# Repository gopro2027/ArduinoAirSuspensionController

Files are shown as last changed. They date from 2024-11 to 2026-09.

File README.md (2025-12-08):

# Open Air Suspension Management (OAS-Man)
(https://oasman.dev) 
<!---![image](https://github.com/user-attachments/assets/ea535981-4f51-4782-8f93-9eb1126dc81b)-->

###  [ discord icon Please click here to join the Discord server](https://discord.gg/pUf7FmHKpg) 
###  [ tutorial icon Click here to view the comprehensive build tutorial and documentation!](https://oasman.dev)
###  [ update icon Click here for the oasman installer/update page](https://oasman.dev/flash)

### Important Info To Potential Creators:
Please join the discord for more specific information before you built it!<br>
There may be important information to share before you begin purchasing parts.<br>

### Overview:
This is intended as a DIY replacement for products such as Airlift 3P/3H ($1500) or Airtek Stage 2+ ($1000) with a build cost of less than $500. Combined with the customizability of open sourced code, I hope this is a tempting option for some DIY-ers out there.<br>
Our goal with this project is to provide the car community with a modern fully customizable well documented air suspension system with a budget build cost in mind, all not bound by the limitations of a single company. The rest of your car is custom to you, why not your air suspension too?<br>
- Want to customize the app to match your ride? You got it.<br>
- Did your proprietary air suspension software stop working and there's no update? Not an issue here!<br>
- Sensor broke in your proprietary manifold and you have to buy a whole new one for $1000? Not an issue here, just replace the sensor for $10.<br>
- Want to use bespoke heavy duty valves but also have a nice user interface? Look no further than OAS-Man!<br>
- Control your system with a PS3/PS4/Xbox controller? Yep, [we have that](https://www.youtube.com/shorts/fbXJVwzc6P0)<br>
- Restomodding an old air suspension system? OAS-Man may be the solution!<br>
- Literally any idea you've ever wanted to try with air suspension? OASMan is the best place to start.<br>

This github repo includes an android app<sup>1</sup> and esp32 code along with some 3d printable files and a PCB. The PCB is pre-made SMD and ready for upload in JLCPCB with assembly so minimal-to-no soldering required. There is also a pre-made touch screen device you can order ($25 to $40) which is used as the dedicated controller<sup>2</sup>. There is an easy to use webpage to upload the software so there is no coding required. You will still need to supply the rest of your system which is not covered in this project, such as struts/bags, tank, compressor, tubing and fittings, ect. So that is what you would need in addition to this, similarly to what you would need for one of the on-the-shelf manifolds. If you are unsure what to purchase, I suggest referencing (or purchasing!) the [Airtekk Stage 1 Kit](https://www.airtekk.com/product-p/uni-stage1-kit.htm) as that will just about cover everything you need.<br>
<sub>1. The mobile app is behind on development and lacks various features of the controller software, and currently only has an android release. Recommended to use the touch screen controller for full functionality.</sub><br>
<sub>2. Please view the tutorial and build instructions for more info.</sub>

### Branch Information:
**main branch = ESP32** (Current full version of OASMan)<br>
**dev branch = ESP32** (Bleeding edge updates to OASMAN)<br>
**nano-v1 branch = Arduino Nano** (outdated, no longer maintained, only exists for legacy purposes)<br>
**Other branches = current dev work** (Other dev work which you can ignore)<br>
<br>
### Folder Information:
**tutorial** - Contains important build instructions (must read)<br>
**OASMan_ESP32** - The main board project<br>
**Wireless_Controller** - The project for the wireless controller of the main board<br>
**builds** - Mobile App Builds (apk's ect)<br>
**ESP32_SHARED_LIBS** - Contains files used between the main board and controller projects. Notably the config file which you may or may not need to edit.<br>
**LCDImageCreatorTool** - Code generator for making images for the tiny 128x64 screen on the manifold.<br>
**MobileApp** - New flutter mobile app using BLE (incomplete at the time of this writing)<br>
**3d Prints** - Contains files for 3d printing (more info in tutorials)<br>
**PCB** - PCB files. More info in tutorial<br>
**PS3_Controller_Tool** - Contains instructions & exe for setting the MAC address of your ps3 controller to work with OASMan<br>
**photos** - photos<br>
<br>

<br>

<!---
**Loose steps:** <br>
1. Order parts, order circuit board on JLPCB website, 3d print parts
2. Solder parts to circuit board, flip all switches to off
    1. For the manifold connector, wire the white wires (abcdefgh) in alphabetical order on the board, so 1 is a, 2 is b, and so on. The 9th wire goes to the spot right above the rest of the wires.
    2. The pressure sensors go in order... 1(manifold) -> FP (board) ... 4 -> RD. In general the order of everything is FRONT PASSENGER, REAR PASSENGER, FRONT DRIVER, REAR DRIVER abbreviatted FP, RP, FD, RD, sorry for the odd order it happened by accident
4. Configure code:
    1. get mac address of HC-06 bluetooth device by using an app or sommething to find it.
    2. Put the mac address in the android code, replacing the old mac address
    3. (Optional) Update the passwords in the app and arduino code if you want
    4. Write code to arduino
5. Circuit board single switch off, on the double switch make the top one on and bottom one off (this will power the arduino by 5v from the buck converter. 12 is bottom switch if you want to use that instead but you can ignore it)
-->
OAS-Man Final v2
<!--![wireless_contoller](https://github.com/user-attachments/assets/ef3c085b-e8ef-4365-bd6b-093a90eec54d)
![manifold](https://github.com/user-attachments/assets/d93784e5-7e5e-4bb0-891a-8a2a8e4d4da0)
![app_airsuspension](https://user-images.githubusercontent.com/7937950/236578835-0e3a208d-48cf-48e8-a882-4479f1afe35c.png)-->
<!--![car_airsuspension](https://user-images.githubusercontent.com/7937950/236578918-bfa39ad6-a3b5-4d52-b36a-be34e8c608af.png)-->
<!--![oasman mascot car](https://github.com/user-attachments/assets/aef9e896-0be0-4203-92d2-81836c27fd5d)-->

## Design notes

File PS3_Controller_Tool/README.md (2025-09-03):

# Videogame Controller Usage
OASMan implements a library called [Bluepad32](https://bluepad32.readthedocs.io/en/latest/) in order to allow a multitude of controllers to connect to our air suspension system!

<br>
Thank you to [ricardoquesada](https://github.com/ricardoquesada/bluepad32) for the creation of this library!

### How to pair a controller
DISCLAIMER: Always store controllers in a safe location when driving so they do not get enabled accidentally while driving. Do not use controllers while driving. Use at your own risk.
1. Put your car in park for pairing. Pairing a new controller may potentially disrupt bluetooth signal, and in the worst case, cause oasman to reboot. This shouldn't pose any safety issues, but please be careful.
3. You need to go into your oasman touch screen control and go to settings and click "Allow New Controller". This will put oasman into pairing mode.
4. Grab your controller and follow the manufacturers instructions on how to put it into pairing/sync mode. You can also find instructions for this on [bluepad32's wiki](https://bluepad32.readthedocs.io/en/latest/supported_gamepads/)
Sometimes there may be issues during syncing new controllers. You may find better results if you disconnect other controllers before trying to sync a new controller.

Once your controller is paired, to reconnect it again, simply turn it on like normal and oasman will accept the connection.

There is an arbitrarily chosen max of 20 paired controllers in OASMan. You can reset all paired controllers in the settings page of the touch screen controller.

Oasman technically supports multiple controllers being connected at the same time.

Not all controllers are supported, such as keyboards, but I did specifically add [support for the wii fit balance board](https://www.instagram.com/p/DNy50Yu3hv6/)

### Special instructions for PS3 Controllers
If you plan to use a ps3 controller, use the sixaxis pair tool to change your mac address of your PS3 controller to your ESP32's mac address<br>
You can use a phone app called nRF Connect to obtain the mac address of the oasman system<br>
<br>

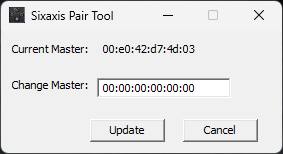
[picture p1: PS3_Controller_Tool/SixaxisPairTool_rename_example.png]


<a href="https://github.com/gopro2027/ArduinoAirSuspensionController/raw/refs/heads/main/PS3_Controller_Tool/SixaxisPairToolSetup-0.3.1.exe">Download Sixaxis Pair Tool here</a><br>
<br>
Additional information that explains why the ps3 controller is special and linux setup: <a href="https://bluepad32.readthedocs.io/en/latest/pair_ds3/">https://bluepad32.readthedocs.io/en/latest/pair_ds3/</a><br>
<br>
### Controller Controls
**L1 + R1**: arm/disarm the controller (armed by default)<br>
**System Button (aka playstation button or xbox button)**: disconnect controller<br>
<br>
Joystick inputs:<br>
**left joystick - left**: air up left side of car<br>
**left joystick - right**:  air out left side of car<br>
**left joystick - up**: air up front side of car<br>
**left joystick - down**: air down front side of car<br>
**right joystick - left**: air out right side of car<br>
**right joystick - right**: air up right side of car<br>
**right joystick - up**: air up rear side of car<br>
**right joystick - down**: air down rear side of car<br>
<br>
**Controllers with only one joystick**: Devices such as the nintendo switch joycon, you can press and hold the **B** button to make your joystick swap from one side to the other while holding it.<br>
<br>
**Wii Fit Balance Board**: Left side controls front of car, right side controls rear of car<br>
<br>
There is also an easter egg. See if you can find it!<br>

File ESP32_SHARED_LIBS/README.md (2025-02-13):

This project is not meant to be compiled and uploaded to an esp32.<br>
This simply contains shared files between the manifold and the controller.<br>
You edit the user_defines.h file in here

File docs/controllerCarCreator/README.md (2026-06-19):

# OAS-Man Car Editor

Web tool for aligning a custom car photo over the controller preset images and uploading
custom car/wheel graphics to the Wireless Controller over USB serial, or exporting
ready-to-compile LVGL C sources for developers. Replaces the Python Tkinter tool at
`Wireless_Controller/tools/imageCreator/car_creator.py`.

The shipped page, `index.html`, is **generated** — don't edit it by hand. Edit the
source files and rebuild.

## Building `index.html`

Requires [Node.js](https://nodejs.org/) (v18+).

```bash
# from docs/controllerCarCreator/
npm install      # one-time: installs esbuild
npm run build    # compiles app.tsx + template.html + preset PNGs -> index.html
```

That's it. `index.html` is a standalone file — open it in Chrome or Edge (no local
server needed). Preset reference images are embedded at build time from
`Wireless_Controller/device_libs/<device>/images/presets/`.

### Rebuild automatically on change

```bash
npm run watch    # rebuilds index.html whenever app.tsx or template.html changes
```

## How the build works

```
app.tsx ────────────────┐
                        ├──►  build.mjs (esbuild + preset embed)  ──►  index.html
template.html ──────────┤
device_libs presets ────┘
```

- **`app.tsx`** — the React app and workflow logic. **Source of truth for behavior.**
- **`template.html`** — the HTML shell: `<head>`, CSS, CDN `<script>` tags (React,
  ReactDOM), preset placeholder, and `<div id="root">`.
- **`build.mjs`** — transpiles/minifies `app.tsx`, scans `device_libs` for preset PNGs,
  base64-embeds them as `window.PRESET_IMAGES`, and writes `index.html`.

## Upload to controller (recommended)

Requires firmware with USB car upload support (current `dev` controller builds).

1. Complete the align-car and align-wheels steps in the editor.
2. On the controller: **Settings → Upload custom car (USB)** → confirm reboot.
3. Plug the controller into your computer with USB.
4. In the editor (Chrome or Edge, `https://` or localhost): **Connect serial** → **Upload to device**.
5. The controller reboots with your custom car on the presets screen.

Custom images are stored on the controller's **LittleFS** flash partition and survive OTA firmware updates.

To remove USB-uploaded images: **Settings → Clear custom car images**.

## Developer fallback (compile-time)

1. Download `img_car_custom.c` and `img_wheels_custom.c` from the editor.
2. Copy them into `Wireless_Controller/src/`.
3. Uncomment `-D CUSTOM_CAR_IMAGE` in `Wireless_Controller/platformio.ini`.
4. Build and flash your controller env.

The editor converts images to **LVGL RGB565A8** in the browser (same format as
[lvgl.io/tools/imageconverter](https://lvgl.io/tools/imageconverter)).

## Files

| File | Committed? | Notes |
| --- | --- | --- |
| `app.tsx` | yes | React source |
| `template.html` | yes | HTML shell + CSS |
| `build.mjs` | yes | Build script + preset bundler |
| `index.html` | yes | **Generated** — do not hand-edit |
| `HOW_IT_WORKS.md` | yes | In-depth architecture doc |
| `node_modules/` | no | gitignored |

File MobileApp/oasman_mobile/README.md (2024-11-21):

# oasman_mobile

A new Flutter project.

## Getting Started

This project is a starting point for a Flutter application.

A few resources to get you started if this is your first Flutter project:

- [Lab: Write your first Flutter app](https://docs.flutter.dev/get-started/codelab)
- [Cookbook: Useful Flutter samples](https://docs.flutter.dev/cookbook)

For help getting started with Flutter development, view the
[online documentation](https://docs.flutter.dev/), which offers tutorials,
samples, guidance on mobile development, and a full API reference.

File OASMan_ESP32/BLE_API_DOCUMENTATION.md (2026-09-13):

# BLE API Documentation - Client Implementation Guide

###### Notice: This documentation was written by AI. Please double check the code if you run into issues, and notify the maintainers

This document provides a complete guide for implementing a BLE client to connect to the OASMan ESP32 Air Suspension Controller. It is based on the implementation patterns used in the Wireless_Controller project.

## Table of Contents

- [Client Implementation Overview](#client-implementation-overview)
- [Complete Client Implementation](#complete-client-implementation)
- [Packet Queue System](#packet-queue-system)
- [Notification Handling](#notification-handling)
- [Sending Commands](#sending-commands)
- [Client State Management](#client-state-management)
- [API Reference](#api-reference)
  - [Service and Characteristics](#service-and-characteristics)
  - [Packet Types](#packet-types)
  - [Constants and Enums](#constants-and-enums)

---

## Client Implementation Overview

The client implementation follows these key patterns:

1. **Packet Queue System**: Thread-safe queue for sending commands (prevents blocking)
2. **Notification-Based Communication**: All responses arrive via characteristic notifications
3. **Status Monitoring**: Tracks connection health via periodic status updates
4. **Authentication Flow**: Must authenticate within 5 seconds of connection
5. **Connection Management**: Handles reconnection, timeouts, and state tracking

For a complete reference implementation, see the Wireless_Controller project code.

---

## Client Implementation Flow

### 1. Initialization

When initializing your BLE client:

- Initialize your BLE stack/library
- Set MTU to 517 bytes before connecting (if supported by your platform)
- Initialize your packet queue system (see Packet Queue System section)
- Set up state variables for tracking connection status, authentication state, and status timeout

**Key State Variables Needed:**

- Connection status flag
- Authentication result state
- Status timeout timestamp
- References to the three characteristics (Status, REST, Valve Control)

### 2. Scanning for Devices

Scan for OASMan devices advertising the service UUID `679425c8-d3b4-4491-9eb2-3e3d15b625f0`.

**Scan Process:**

- Use active scanning for better discovery results
- Filter scan results by checking if devices advertise the OASMan service UUID
- Optional: Maintain a blacklist of devices that previously failed authentication to avoid repeated connection attempts
- Store found devices for connection attempts
- Recommended scan duration: 5 seconds

**What to do with found devices:**

- Store them in a queue or list for connection attempts
- Filter out devices from your auth blacklist (if implemented)

### 3. Connection

Connect to a discovered OASMan device:

**Connection Steps:**

1. Create a BLE client instance
2. Set up security/authentication callbacks if your platform requires it
3. Connect to the device (use async connection if available, with a 1-second timeout)
4. Wait for connection to complete (check connection status in a loop with timeout)
5. If connection fails, cancel and retry

**After Connection:**

1. Discover the service using UUID `679425c8-d3b4-4491-9eb2-3e3d15b625f0`
2. Get references to the three characteristics:
   - Status: `66fda100-8972-4ec7-971c-3fd30b3072ac`
   - REST: `f573f13f-b38e-415e-b8f0-59a6a19a4e02`
   - Valve Control: `e225a15a-e816-4e9d-99b7-c384f91f273b`
3. Subscribe to notifications on all three characteristics (use the same callback for all)
4. Add small delays (50ms) between characteristic subscriptions if needed

**Connection Callbacks:**

- Implement connection/disconnection callbacks to track connection state changes
- Handle security/authentication callbacks if your platform requires them

---

## Packet Queue System

The packet queue system allows non-blocking command sending, which is essential for responsive applications. Instead of blocking while waiting for writes to complete, commands are queued and sent sequentially in your main loop.

### Queue Pattern

**Purpose:** Decouple command creation from BLE transmission to avoid blocking your application.

**How it works:**

1. Your application code creates packets and adds them to a queue (non-blocking operation)
2. Your main loop processes the queue and sends packets one at a time to the REST characteristic
3. Use thread-safe queue operations if your application uses multiple threads

**Queue Functions Needed:**

- `sendRestPacket(packet)` - Add a packet to the queue (called from anywhere)
- `getBTRestPacketToSend(packet)` - Retrieve next packet from queue (called from main loop)
- `clearPackets()` - Clear all queued packets (useful on disconnect/reconnect)

**Queue Size:** Recommended maximum of 10 packets to prevent memory issues and ensure timely command processing.

**Thread Safety:** If your application uses multiple threads, protect queue access with mutexes/semaphores. If single-threaded, simple flags or counters are sufficient.

---

## Notification Handling

All responses arrive via characteristic notifications. Use a single callback function to handle notifications from both Status and REST characteristics.

### Notification Callback Pattern

**Single Callback for All Characteristics:**

- Use one callback function for all three characteristics
- Check the characteristic UUID in the callback to determine which characteristic sent the notification
- Process data based on which characteristic it came from

### Status Characteristic Notifications

**When:** Received approximately every 250ms after authentication

**What to do:**

1. Reset your status timeout timer (set timeout to current time + 5 seconds)
2. Set `hasReceivedStatus = true` (track that you've received at least one status)
3. Parse the `StatusPacket` structure:
   - Extract wheel pressures from `args16()[0-3]` (Front Passenger, Rear Passenger, Front Driver, Rear Driver)
   - Extract tank pressure from `args16()[4]`
   - Extract AI percentage from `args8()[10]`
   - `args8()[11]` is reserved (formerly AI ready bitset; removed in manifold schema 5) and reads 0
   - Extract status bitset from `args32()[3]` and parse individual flags
4. Update your application state/UI with the new values

**Status Bitset Parsing:** Each bit represents a different status flag (see [StatusPacketBittset](#constants-and-enums) in API Reference). Extract individual flags using bit shifting: `(statusBits >> StatusPacketBittset::FLAG_NAME) & 1`

### REST Characteristic Notifications

**When:** Received as responses to commands you send, or for authentication responses

**What to do:**

1. Reset your status timeout timer
2. Cast the data to `BTOasPacket*` and check the `cmd` field
3. **If `cmd == AUTHPACKET`:**
   - Extract `authResult` from the packet
   - Update your authentication state
   - Store the authenticated device address if successful
4. **If authenticated and `cmd == PRESETREPORT`:**
   - Parse `PresetPacket` to extract profile pressures
   - Update your profile data storage
5. **If authenticated and `cmd == GETCONFIGVALUES`:**
   - Parse `ConfigValuesPacket` to extract all configuration values
   - Update your configuration display
6. **If authenticated and `cmd == UPDATESTATUSREQUEST`:**
   - Extract status string from the packet
   - Display firmware update status to user

**Important:** Only process command responses (PRESETREPORT, GETCONFIGVALUES, etc.) when `authenticationResult == AUTHRESULT_SUCCESS`.

---

## Sending Commands

Commands are sent via the packet queue system (see [Packet Queue System](#packet-queue-system)).

### Command Flow

1. Create the appropriate packet type with required parameters (see [Packet Types](#packet-types) in API Reference)
2. Add packet to queue using `sendRestPacket(packet)`
3. Your main loop retrieves packets from queue and writes them to the REST characteristic
4. Responses arrive via REST characteristic notifications (see [Notification Handling](#notification-handling))

### Common Command Patterns

**Air Control:**

- `AirupQuickPacket` - Load profile then air up (main method)

**Preset Management:**

- `PresetPacket` - Request preset data (returns via notification)
- `SaveCurrentPressuresToProfilePacket` - Save current pressures to a profile
- `ReadProfilePacket` - Load profile settings
- `BaseProfilePacket` - Set base profile

**Configuration:**

- `ConfigValuesPacket` - Get or set system configuration values
  - Set first parameter to `false` to read only
  - Set first parameter to `true` and fill values to save

**Feature Toggles (via ConfigValuesPacket):**

- Rise on start, maintain pressure, air-out on shutoff, height sensor mode, safety mode, AI enabled are set via `ConfigValuesPacket` with `setValues = true` and the appropriate bits in `configFlagsBits` (see ConfigFlagsBit enum).

**Wheel Pressure:**

See [Packet Types](#packet-types) section for complete list and parameter details.

### Direct Valve Control

Valves can be controlled directly via the Valve Control characteristic without using the packet system.

**Process:**

1. Maintain a 32-bit integer where each bit represents a valve (bit 0 = valve 0, bit 1 = valve 1, etc.)
2. Set bits to 1 to open valves, 0 to close valves
3. Only send when the value changes (optimization)
4. Write 4 bytes (little-endian uint32_t) directly to Valve Control characteristic
5. Server tracks previous state and only toggles valves that changed

**Example State Management:**

- Track previous valve state
- Compare current desired state with previous
- Only write to characteristic when state changes
- This reduces unnecessary BLE traffic

---

## Client State Management

### Main Loop Pattern

Your main loop should handle several tasks:

**When Connected:**

1. **Send Queued Packets:** Retrieve packets from queue and write to REST characteristic (one at a time)
2. **Update Valve Control:** Check if valve state changed, and if so, write to Valve Control characteristic
3. **Check Status Timeout:** If `hasReceivedStatus` is true and current time exceeds `timeoutMS`, disconnect (connection lost)
4. **Monitor Connection:** Check if connection is still active (some platforms provide `isConnected()` methods)

**When Not Connected:**

1. **Scan for Devices:** If scanning is allowed, start a scan
2. **Process Discovered Devices:** Attempt to connect to found devices from your queue/list
3. **Handle Reconnection:** If connection fails, retry or start new scan

**Connection State Checks:**

- Monitor connection status regularly
- Handle disconnection callbacks gracefully
- Clear packet queue on disconnect
- Reset state variables (authentication, status tracking, etc.)

### Status Timeout Management

**Purpose:** Detect when connection is lost even if BLE stack doesn't notify you immediately.

**How it works:**

1. Set `hasReceivedStatus = false` initially
2. On first status notification, set `hasReceivedStatus = true` and `timeoutMS = currentTime + 5000`
3. On each subsequent status notification, reset `timeoutMS = currentTime + 5000`
4. In main loop, check: if `hasReceivedStatus && currentTime > timeoutMS`, then disconnect

**Why:** Status updates arrive every ~250ms when connected. If no status is received for 5 seconds, the connection is likely lost.

### Disconnection Handling

**When disconnecting:**

1. Set connection state to disconnected
2. Stop any active scans
3. Clear packet queue
4. Reset state variables:
   - `connected = false`
   - `hasReceivedStatus = false`
   - `authenticationResult = AUTHRESULT_WAITING`
5. Clean up client resources (cancel connection, delete client instance)
6. Allow scanning again for reconnection
7. Optionally: Show user notification about disconnection reason (auth failed, timeout, etc.)

---

## API Reference

### Service and Characteristics

All packets sent via the REST characteristic use the `BTOasPacket` structure:

```cpp
struct BTOasPacket {
    uint16_t cmd;          // BTOasIdentifier enum value
    uint8_t sender;        // unused (0)
    uint8_t recipient;     // Recipient ID (0 for broadcast)
    uint8_t args[100];     // Payload data (variable length)
};
```

**Total Size**: 104 bytes (`BTOAS_PACKET_SIZE`)

**Note**: The `args` array can be accessed as different types:

- `args8()` - Access as `uint8_t` array
- `args16()` - Access as `uint16_t` array
- `args32()` - Access as `uint32_t` array

All multi-byte values are **little-endian**.

---

### Packet Types

### Client-to-Server Packets (Commands)

#### AUTHPACKET

**Command ID**: `22`  
**Purpose**: Authenticate with the device

**Structure**:

- `args32()[0]`: `uint32_t blePasskey` - Device passkey
- `args32()[1]`: `AuthResult authResult` - Set to `AUTHRESULT_WAITING` (0) for auth request

**Usage**:

1. Create packet with `authResult = AUTHRESULT_WAITING`
2. Write to REST characteristic
3. Server responds with same packet but `authResult` set to `SUCCESS` or `FAIL`

**Example**:

```cpp
AuthPacket packet(passkey, AUTHRESULT_WAITING);
// Write packet.tx() (104 bytes) to REST characteristic

---

#### SAVETOPROFILE

**Command ID**: `5`  
**Purpose**: Save current profile settings to specified profile index

**Structure**:

- `args32()[0]`: `int profileIndex` - Profile number to save to

---

#### READPROFILE

**Command ID**: `6`  
**Purpose**: Load pressure settings from specified profile

**Structure**:

- `args32()[0]`: `int profileIndex` - Profile number to read

**Response**: Server loads the profile internally (no packet response)

---

#### AIRUPQUICK

**Command ID**: `7`  
**Purpose**: Load profile then air up (main air up method)

**Structure**:

- `args32()[0]`: `int profileIndex` - Profile to load and air up to

---

#### BASEPROFILE

**Command ID**: `8`  
**Purpose**: Set the base profile

**Structure**:

- `args32()[0]`: `int profileIndex` - Profile to set as base

---

#### RAISEONPRESSURESET

**Command ID**: `11`  
**Purpose**: Enable/disable automatic raise when pressure is set

**Structure**:

- `args32()[0]`: `bool enable` - 1 to enable, 0 to disable

---

#### REBOOT

**Command ID**: `12`  
**Purpose**: Reboot the device

**Structure**: No parameters

---

#### CALIBRATE

**Command ID**: `13`  
**Purpose**: Calibrate system (feature unfinished)

**Structure**: No parameters

---

#### STARTWEB

**Command ID**: `14`  
**Purpose**: Start OTA update mode with WiFi credentials

**Structure**:

- `args[0-32]`: `char[]` - WiFi SSID (null-terminated, max `WIFI_SSID_MAX_LEN` = 32 bytes)
- `args[33-97]`: `char[]` - WiFi Password at `STARTWEB_PASSWORD_INDEX` (null-terminated, max `WIFI_PASSWORD_MAX_LEN` = 64 bytes; longer input is truncated)
- `args[98]`: `uint8_t` - `1` = allow a one-time insecure HTTP update (`STARTWEB_INSECURE_FLAG_INDEX`)

Breaking change from the old 50/50 split (`args[0-49]` / `args[50-99]`): manifold, controller and app must run matching firmware for STARTWEB.

**Example**:

```cpp
StartwebPacket packet("MyWiFi", "password123");
```

---

#### SAVECURRENTPRESSURESTOPROFILE

**Command ID**: `17`  
**Purpose**: Save current wheel pressures to a profile

**Structure**:

- `args32()[0]`: `int profileIndex` - Profile number to save current pressures to

---

#### PRESETREPORT

**Command ID**: `18`  
**Purpose**: Request pressure values for a specific profile

**Structure**:

- `args32()[0]`: `int profileIndex` - Profile to query

**Response**: Server responds with `PresetPacket` containing profile pressures

---

#### GETCONFIGVALUES

**Command ID**: `21`  
**Purpose**: Get or set system configuration values

**Structure**:

- `args32()[0]`: `uint32_t systemShutoffTimeM` - System shutoff time in minutes
- `args32()[1]`: `uint32_t configFlagsBits` - User config flags (see ConfigFlagsBit enum)
- `args16()[4]`: `uint16_t pressureSensorMax` - Maximum pressure sensor value
- `args16()[5]`: _retired_ (formerly `bagVolumePercentage`) 
- `args8()[12+0]`: `uint8_t bagMaxPressure` - Maximum bag pressure
- `args8()[12+1]`: `uint8_t compressorOnPSI` - Compressor turn-on PSI
- `args8()[12+2]`: `uint8_t compressorOffPSI` - Compressor turn-off PSI
- `args8()[12+3]`: `bool setValues` - Set to 1 to write values, 0 to only read
- `args8()[12+4]`: `uint8_t rfButtonA` - RF button A preset assignment (read-only)
- `args8()[12+5]`: `uint8_t rfButtonB` - RF button B preset assignment (read-only)
- `args8()[12+6]`: `uint8_t rfButtonC` - RF button C preset assignment (read-only)
- `args8()[12+7]`: `uint8_t rfButtonD` - RF button D preset assignment (read-only)
- `args8()[12+8]`: `uint8_t AirUpBagStretchTriggerBelowPressure` - Air up bag stretch trigger pressure
- `args8()[12+9]`: `uint8_t AirUpBagStretchPressure` - Air up bag stretch pressure
- `args8()[12+10]`: `uint8_t compressorCrankOffset` - Seconds the compressor is held off after accessory power arrives (default 5)
- `args32()[6]`: `AuxillaryOutputModePayload auxillaryOutputConfig` - Auxillary output mode/timeUnit/time/interval (4 bytes)

**ConfigFlagsBit** (bits in `configFlagsBits`): Bit 0 = CONFIG_MAINTAIN_PRESSURE, 1 = CONFIG_RISE_ON_START, 2 = CONFIG_AIR_OUT_ON_SHUTOFF, 3 = CONFIG_HEIGHT_SENSOR_MODE, 4 = CONFIG_SAFETY_MODE, 5 = CONFIG_AI_STATUS_ENABLED.

**Usage**:

- To read: Set `setValues = 0`, write packet, receive response with all values
- To write: Set `setValues = 1`, fill in desired values, write packet, receive confirmation

---

#### COMPRESSORSTATUS

**Command ID**: `24`  
**Purpose**: Enable/disable compressor override

**Structure**:

- `args32()[0]`: `bool enable` - 1 to enable override, 0 to disable

---

#### TURNOFF

**Command ID**: `25`  
**Purpose**: Force system shutdown

**Structure**: No parameters

---

#### DETECTPRESSURESENSORS

**Command ID**: `27`  
**Purpose**: Detect and learn pressure sensors, then reboot

**Structure**: No parameters

**Note**: Triggers system reboot after detection

---

#### RESETAIPKT

**Command ID**: `29`  
**Purpose**: Reset AI pressure data

**Structure**: No parameters

---

#### BP32PKT

**Command ID**: `30`  
**Purpose**: Control Bluepad32 gamepad controller features

**Structure**:

- `args16()[0]`: `BP32CMD command` - Command type:
  - `0` = `BP32CMD_ENABLE_NEW_CONN` - Enable/disable new controller connections
  - `1` = `BP32CMD_FORGET_DEVICES` - Forget all paired controllers
  - `2` = `BP32CMD_DISCONNECT_DEVICES` - Disconnect all controllers
- `args16()[1]`: `bool value` - Value for enable/disable commands (ignored for forget/disconnect)

---

#### BROADCASTNAME

**Command ID**: `35`  
**Purpose**: Change the BLE broadcast name

**Structure**:

- `args[0-7]`: `char[]` - New broadcast name (max 8 characters, null-terminated)

**Example**:

```cpp
BroadcastNamePacket packet("MyOASMan");
```

---

#### UPDATESTATUSREQUEST

**Command ID**: `36`  
**Purpose**: Request firmware update status

**Structure**: No parameters (empty packet)

**Response**: Server responds with `UpdateStatusRequestPacket` containing status string:

- `"v<version>"` - Current version on success
- `"[F] FW DL"` - Failed to download firmware
- `"[F] Install"` - Failed to install
- `"[F] Finding"` - Failed to find version
- `"[F] No WiFi"` - Failed WiFi connection

---

#### RFCOMMAND

**Command ID**: `37`  
**Purpose**: Control RF receiver and button assignments

**Structure**:

- `args32()[0]`: `RfCommandType commandType`:
  - `1` = `RF_COMMAND_CHIP_CMD` - RF chip command
  - `2` = `RF_COMMAND_BUTTON_ASSIGN` - Assign button to preset

**For RF_COMMAND_CHIP_CMD**:

- `args32()[1]`: `RfCommandChipNumber chipCommand`:
  - `1` = `RF_CMD_DELETE` - Delete learned codes
  - `2` = `RF_CMD_LEARN_MOMENTARY` - Learn momentary mode
  - `3` = `RF_CMD_LEARN_TOGGLE` - Learn toggle mode
  - `4` = `RF_CMD_LEARN_RADIOBUTTON` - Learn radio button mode
- `args32()[2]`: Ignored

**For RF_COMMAND_BUTTON_ASSIGN**:

- `args32()[1]`: `RfCommandButtonNumber buttonNumber`:
  - `1` = `RF_BUTTON_A`
  - `2` = `RF_BUTTON_B`
  - `3` = `RF_BUTTON_C`
  - `4` = `RF_BUTTON_D`
- `args32()[2]`: `int presetNumber` - Preset profile to assign (0-based)

**Example - Learn RF code**:

```cpp
RfCommandPacket packet(RF_COMMAND_CHIP_CMD, RF_CMD_LEARN_MOMENTARY, 0);
```

**Example - Assign button to preset**:

```cpp
RfCommandPacket packet(RF_COMMAND_BUTTON_ASSIGN, RF_BUTTON_A, 2); // Assign button A to preset 2
```

---

### Server-to-Client Packets (Responses/Updates)

#### STATUSREPORT (Status Packet)

**Command ID**: `1`  
**Purpose**: Periodic status updates sent via Status characteristic

**Frequency**: Every ~250ms to all authenticated clients

**Structure**:

- `args16()[0]`: `uint16_t` - Front Passenger pressure (PSI)
- `args16()[1]`: `uint16_t` - Rear Passenger pressure (PSI)
- `args16()[2]`: `uint16_t` - Front Driver pressure (PSI)
- `args16()[3]`: `uint16_t` - Rear Driver pressure (PSI)
- `args16()[4]`: `uint16_t` - Tank pressure (PSI)
- `args8()[10]`: `uint8_t` - AI percentage (0-100). Progress toward full AI-weighted valve timing: 100% once every model has `AI_LEARN_RATIO_NUM` (150) samples, i.e. the AI is fully driving. Not progress toward the `LEARN_SAVE_COUNT` (300) collection ceiling. As of manifold schema 5.
- `args8()[11]`: `uint8_t` - reserved, always 0 (formerly AI ready bitset; removed in manifold schema 5, which blends the AI in gradually by `trainedSampleCount` rather than exposing a per-model ready flag). Byte kept for wire compatibility.
- `args32()[3]`: `uint32_t` - Status bitset (see below)

**Status Bitset Flags** (bits in `args32()[3]`). Only live status flags; user-config toggles (maintain pressure, rise on start, etc.) are in `ConfigValuesPacket` as `configFlagsBits`.

- Bit 0: `COMPRESSOR_FROZEN` - Compressor is frozen (StatusPacketBittset::COMPRESSOR_FROZEN = 0)
- Bit 1: `COMPRESSOR_STATUS_ON` - Compressor is running (StatusPacketBittset::COMPRESSOR_STATUS_ON = 1)
- Bit 2: `ACC_STATUS_ON` - Vehicle ACC is on (StatusPacketBittset::ACC_STATUS_ON = 2)
- Bit 3: `TIMER_STATUS_EXPIRED` - Keep-alive timer expired (StatusPacketBittset::TIMER_STATUS_EXPIRED = 3)
- Bit 4: `CLOCK` - Toggles every 250ms (StatusPacketBittset::CLOCK = 4)
- Bit 5: `EBRAKE_STATUS_ON` - Emergency brake is on (StatusPacketBittset::EBRAKE_STATUS_ON = 5)
- Bit 6: `ADJUSTMENT_IN_PROGRESS` - A corner is actively filling/dumping to a target, i.e. `isAnyWheelActive()` (StatusPacketBittset::ADJUSTMENT_IN_PROGRESS = 6)

**Parsing Example**:

```cpp
uint32_t statusBits = statusPacket->args32()[3].i;
bool compressorOn = (statusBits >> StatusPacketBittset::COMPRESSOR_STATUS_ON) & 1;
bool accOn = (statusBits >> StatusPacketBittset::ACC_STATUS_ON) & 1;
```

**Usage**: Subscribe to notifications on Status characteristic to receive updates

---

#### PRESETREPORT (Preset Packet)

**Command ID**: `18`  
**Purpose**: Response to `PRESETREPORT` request, contains profile pressure values

**Structure**:

- `args16()[0]`: `uint16_t` - Front Passenger pressure (PSI)
- `args16()[1]`: `uint16_t` - Rear Passenger pressure (PSI)
- `args16()[2]`: `uint16_t` - Front Driver pressure (PSI)
- `args16()[3]`: `uint16_t` - Rear Driver pressure (PSI)
- `args16()[4]`: `uint16_t` - Profile index

**Usage**: Received via REST characteristic notification in response to `PRESETREPORT` command

---

#### GETCONFIGVALUES Response

**Command ID**: `21`  
**Purpose**: Response containing all configuration values

**Structure**: Same as request (see GETCONFIGVALUES above)

**Usage**: Received via REST characteristic notification after sending `GETCONFIGVALUES`

---

#### AUTHPACKET Response

**Command ID**: `22`  
**Purpose**: Authentication response

**Structure**: Same as request, but `args32()[1]` contains `AUTHRESULT_SUCCESS` (1) or `AUTHRESULT_FAIL` (2)

---

#### UPDATESTATUSREQUEST Response

**Command ID**: `36`  
**Purpose**: Firmware update status response

**Structure**:

- `args[0-N]`: `char[]` - Status message string (null-terminated)

---

#### IDLE

**Command ID**: `0`  
**Purpose**: Empty/placeholder packet

**Structure**: All zeros

---

## Client Usage Guide

### Connection Flow

1. **Scan and Connect**

   - Initialize BLE: `BLEDevice::init("ClientName")`
   - Set MTU: `NimBLEDevice::setMTU(517)` (recommended before connecting)
   - Scan for devices advertising service UUID `679425c8-d3b4-4491-9eb2-3e3d15b625f0`
   - Use active scanning: `setActiveScan(true)`
   - Scan interval/window: 100ms recommended
   - Filter results: Check `advertisedDevice->isAdvertisingService(serviceUUID)`
   - Connect: `pClient->connect(advertisedDevice, true, true)` (async, use timeout)
   - Connection timeout: 1 second recommended (check `isConnected()` in loop)

2. **Discover Services and Characteristics**

   - Discover primary service: `679425c8-d3b4-4491-9eb2-3e3d15b625f0`
   - Discover characteristics:
     - Status: `66fda100-8972-4ec7-971c-3fd30b3072ac`
     - REST: `f573f13f-b38e-415e-b8f0-59a6a19a4e02`
     - Valve Control: `e225a15a-e816-4e9d-99b7-c384f91f273b`

3. **Subscribe to Notifications**

   - Subscribe to Status characteristic notifications using `subscribe(true, notifyCallback, false)`
   - Subscribe to REST characteristic notifications using `subscribe(true, notifyCallback, false)`
   - Both characteristics can use the same callback function - check UUID in callback to differentiate
   - Alternative: Manually write `0x0100` (little-endian 16-bit: notification enabled) to client configuration handles

4. **Authenticate** (Must complete within 5 seconds)

   - Create `AUTHPACKET` with passkey and `AUTHRESULT_WAITING`
   - Write to REST characteristic value handle (`0x000c`) using `writeValue(data, size, true)`
   - Wait for notification with authentication result (poll or use callback)
   - Server responds via REST characteristic notification with same packet but `authResult` updated
   - If `AUTHRESULT_SUCCESS`, proceed; if `AUTHRESULT_FAIL`, disconnect and optionally blacklist device
   - Timeout: Disconnect if no response within 5 seconds

5. **Send Commands**

   - Create appropriate packet structure
   - Write `packet.tx()` (104 bytes) to REST characteristic value handle (`0x000c`)
   - Monitor REST characteristic notifications for responses

6. **Receive Updates**
   - Status updates arrive automatically via Status characteristic notifications (~250ms interval)
   - Command responses arrive via REST characteristic notifications

### Direct Valve Control

To directly control valves without using commands:

1. Write 4 bytes (little-endian uint32_t) to Valve Control characteristic value handle (`0x000f`)
2. Each bit represents one valve (bit 0 = valve 0, bit 1 = valve 1, etc.)
3. `1` = open valve, `0` = close valve
4. Server tracks previous valve state and only toggles valves that changed

**Example**:

```cpp
unsigned int valveControlValue = 0;
// Open valve 0
valveControlValue |= (1 << 0);
// Open valves 0 and 1
valveControlValue |= (1 << 1);

// Only send when value changes (client-side optimization)
if (previousValveValue != valveControlValue) {
    pRemoteChar_ValveControl->writeValue((uint8_t*)&valveControlValue, 4, true);
    previousValveValue = valveControlValue;
}
```

**Note**: Some mobile apps may send less than 4 bytes. The server handles this by zero-padding, but clients should always send 4 bytes.

### Status Monitoring and Timeouts

**Status Update Timeout**: After authentication, clients must receive Status characteristic notifications. If no status update is received for 5 seconds, the connection is considered lost. The client should:

- Track the last received status timestamp
- Reset the timeout on each status notification received
- Disconnect and reconnect if timeout expires

**Note**: The server sends status updates approximately every 250ms to all authenticated clients.

### Error Handling

- **Authentication Timeout**: If authentication is not completed within 5 seconds of connection, the device will disconnect (unless client is a registered controller)
- **Status Timeout**: If no status update is received for 5 seconds after first status, connection is considered lost
- **Invalid Commands**: Invalid or malformed packets are ignored (no response sent)
- **Connection Loss**: If disconnected, reconnect and re-authenticate
- **Write Failures**: Always check return value of write operations; if write fails, connection may be lost

### Best Practices

1. **Always authenticate first** before sending other commands
2. **Subscribe to notifications** on both Status and REST characteristics using `subscribe(true, notifyCallback, false)`
3. **Handle notifications asynchronously** - responses may arrive at any time in notification callbacks
4. **Use Status updates** for real-time monitoring instead of polling - they arrive automatically every ~250ms
5. **Queue packets** - Use a packet queue mechanism to send commands sequentially and avoid blocking
6. **Track status timeouts** - Monitor last received status timestamp to detect connection loss
7. **Use `writeValue` with response required** - Set the `response` parameter to `true` when writing to characteristics
8. **Set MTU before connecting** - Request MTU of 517 bytes before connection for optimal performance
9. **Handle connection callbacks** - Implement connection/disconnection callbacks to handle state changes
10. **Blacklist failed auth attempts** - Track devices that fail authentication to avoid repeated attempts

### Connection Timing Details

- **Connection timeout**: 1 second (recommended client-side timeout for connection attempts)
- **Authentication wait**: Up to 5 seconds (server-side timeout)
- **Status update interval**: ~250ms
- **Status timeout**: 5 seconds (timeout if no status received)
- **Write delays**: Add small delays (10-50ms) between writes if experiencing issues

### Packet Construction Examples (C++)

```cpp
// Example 1: Create an AIRUP packet using helper class
AirupPacket pkt;
sendRestPacket(&pkt); // Queue packet for sending

// Example 2: Create a preset load command
AirupQuickPacket pkt(presetIndex); // presetIndex is 0-based
sendRestPacket(&pkt);

// Example 3: Set a config toggle (e.g. rise on start) via ConfigValuesPacket
// Update util_configValues._configFlagsBits() with the desired bits, then:
// sendConfigValuesPacket(true);

// Example 4: Create a profile save command
SaveCurrentPressuresToProfilePacket pkt(profileIndex); // 0-based index
sendRestPacket(&pkt);

// Example 5: Request preset data
PresetPacket pkt(presetIndex, 0, 0, 0, 0); // Request preset data
sendRestPacket(&pkt);

// Example 6: Authentication packet
AuthPacket authPacket(passkey, AUTHRESULT_WAITING);
pRemoteChar_Rest->writeValue(authPacket.tx(), BTOAS_PACKET_SIZE, true);

// Example 7: Config values request (read-only)
ConfigValuesPacket pkt(false, 0, 0, 0, 0, 0, 0, 0, 0, 0, 0, 0, 0);
sendRestPacket(&pkt);
```

**Note**: Most clients use a packet queue system. The `sendRestPacket()` function queues packets that are sent in the main loop via `writeValue()`.

### Packet Parsing Examples (C++)

```cpp
// Example 1: Parse a StatusPacket from Status characteristic notification
void notifyCallback(BLERemoteCharacteristic* pBLERemoteCharacteristic,
                    uint8_t* pData, size_t length, bool isNotify) {

    if (pBLERemoteCharacteristic->getUUID() == STATUS_CHAR_UUID) {
        StatusPacket* status = (StatusPacket*)pData;

        // Update current pressures
        currentPressures[WHEEL_FRONT_PASSENGER] = status->args16()[WHEEL_FRONT_PASSENGER].i;
        currentPressures[WHEEL_REAR_PASSENGER] = status->args16()[WHEEL_REAR_PASSENGER].i;
        currentPressures[WHEEL_FRONT_DRIVER] = status->args16()[WHEEL_FRONT_DRIVER].i;
        currentPressures[WHEEL_REAR_DRIVER] = status->args16()[WHEEL_REAR_DRIVER].i;
        currentPressures[_TANK_INDEX] = status->args16()[_TANK_INDEX].i;

        // Update status bits
        statusBittset = status->args32()[3].i;
        AIPercentage = status->args8()[10].i;
        // args8()[11] is reserved (formerly AI ready bitset) and reads 0

        // Check individual status flags (live status only; user config from GETCONFIGVALUES)
        bool compressorOn = (statusBittset >> StatusPacketBittset::COMPRESSOR_STATUS_ON) & 1;
        bool accOn = (statusBittset >> StatusPacketBittset::ACC_STATUS_ON) & 1;
        bool compressorFrozen = (statusBittset >> StatusPacketBittset::COMPRESSOR_FROZEN) & 1;
        // ... etc

        // Reset timeout on successful status receipt
        timeoutMS = millis() + 5000;
    }

    // Example 2: Parse REST characteristic notifications
    if (pBLERemoteCharacteristic->getUUID() == REST_CHAR_UUID) {
        BTOasPacket* pkt = (BTOasPacket*)pData;

        // Handle authentication response
        if (pkt->cmd == AUTHPACKET) {
            AuthResult result = ((AuthPacket*)pkt)->getBleAuthResult();
            if (result == AUTHRESULT_SUCCESS) {
                authenticationResult = result;
            }
        }

        // Handle preset response
        if (pkt->cmd == PRESETREPORT) {
            PresetPacket* preset = (PresetPacket*)pkt;
            int profileIndex = preset->getProfile();
            profilePressures[profileIndex][WHEEL_FRONT_PASSENGER] = preset->args16()[WHEEL_FRONT_PASSENGER].i;
            profilePressures[profileIndex][WHEEL_REAR_PASSENGER] = preset->args16()[WHEEL_REAR_PASSENGER].i;
            profilePressures[profileIndex][WHEEL_FRONT_DRIVER] = preset->args16()[WHEEL_FRONT_DRIVER].i;
            profilePressures[profileIndex][WHEEL_REAR_DRIVER] = preset->args16()[WHEEL_REAR_DRIVER].i;
            profileUpdated = true;
        }

        // Handle config values response
        if (pkt->cmd == GETCONFIGVALUES) {
            ConfigValuesPacket* config = (ConfigValuesPacket*)pkt;
            // Extract config values using helper methods
            uint8_t bagMaxPressure = *config->_bagMaxPressure();
            uint32_t shutoffTime = *config->_systemShutoffTimeM();
            uint8_t configFlags = *config->_configFlagsBits();
            bool maintainPressure = (configFlags & (1 << ConfigFlagsBit::CONFIG_MAINTAIN_PRESSURE)) != 0;
            // ... etc
        }
    }
}
```

---

### Constants and Enums

### Characteristic Handles

- Status Value: `0x0009`
- Status Client Config: `0x000a`
- REST Value: `0x000c`
- REST Client Config: `0x000d`
- Valve Control Value: `0x000f`
- Valve Control Client Config: `0x0010`

### Packet Sizes

- Standard Packet: 104 bytes (`BTOAS_PACKET_SIZE`)
- Valve Control: 4 bytes

### Wheel Indices

- `0` = Front Passenger (`WHEEL_FRONT_PASSENGER`)
- `1` = Rear Passenger (`WHEEL_REAR_PASSENGER`)
- `2` = Front Driver (`WHEEL_FRONT_DRIVER`)
- `3` = Rear Driver (`WHEEL_REAR_DRIVER`)
- `4` = Tank (`_TANK_INDEX`) - Used in StatusPacket for tank pressure

### Timeouts

- **Authentication**: 5 seconds (server disconnects if not authenticated)
- **Status Update Interval**: ~250ms (server sends status updates)
- **Status Timeout**: 5 seconds (client should disconnect if no status received)
- **Connection Timeout**: 1 second (recommended client-side connection attempt timeout)

---

## Additional Notes

### Data Format

- All multi-byte integers are **little-endian**
- String fields are **null-terminated**
- Packet size is fixed at **104 bytes** (`BTOAS_PACKET_SIZE`)

### Connection Limits

- The device supports up to **5 simultaneous connections**
- Each connection is tracked separately with its own authentication state

### MTU Size

- Maximum MTU size is **517 bytes** (if negotiated)
- Server requests MTU of 517 bytes during connection
- Packets are designed for minimum 23-byte MTU (default BLE MTU)
- Client should set MTU to 517 before connecting: `NimBLEDevice::setMTU(517)`

### Important Behaviors

- **Some commands trigger system reboots**: `DETECTPRESSURESENSORS`, `STARTWEB`, `REBOOT`
- **RF button assignments**: Can only be read via `GETCONFIGVALUES`, but must be set via `RFCOMMAND`
- **Write responses**: Always use `writeValue(data, size, true)` - the `true` parameter is required with BTStack
- **Connection parameters**: Server requests 12-24ms connection interval after connection
- **Scan parameters**: Use active scanning (setActiveScan(true)) for better discovery

### Enums

```cpp
enum BTOasIdentifier {
    IDLE = 0,
    STATUSREPORT = 1,
    AIRUP = 2,
    AIROUT = 3,
    AIRSM = 4,
    SAVETOPROFILE = 5,
    READPROFILE = 6,
    AIRUPQUICK = 7,
    BASEPROFILE = 8,
    SETAIRHEIGHT = 9,
    RAISEONPRESSURESET = 11,
    REBOOT = 12,
    CALIBRATE = 13,
    STARTWEB = 14,
    ASSIGNRECEPIENT = 15,
    // 16 retired (formerly MessagePacket); do not reuse
    SAVECURRENTPRESSURESTOPROFILE = 17,
    PRESETREPORT = 18,
    GETCONFIGVALUES = 21,
    AUTHPACKET = 22,
    COMPRESSORSTATUS = 24,
    TURNOFF = 25,
    DETECTPRESSURESENSORS = 27,
    RESETAIPKT = 29,
    BP32PKT = 30,
    BROADCASTNAME = 35,
    UPDATESTATUSREQUEST = 36,
    RFCOMMAND = 37
};

enum StatusPacketBittset {
    COMPRESSOR_FROZEN = 0,
    COMPRESSOR_STATUS_ON = 1,
    ACC_STATUS_ON = 2,
    TIMER_STATUS_EXPIRED = 3,
    CLOCK = 4,
    EBRAKE_STATUS_ON = 5,
    ADJUSTMENT_IN_PROGRESS = 6
};

enum ConfigFlagsBit {
    CONFIG_MAINTAIN_PRESSURE = 0,
    CONFIG_RISE_ON_START = 1,
    CONFIG_AIR_OUT_ON_SHUTOFF = 2,
    CONFIG_HEIGHT_SENSOR_MODE = 3,
    CONFIG_SAFETY_MODE = 4,
    CONFIG_AI_STATUS_ENABLED = 5
};

enum AuthResult {
    AUTHRESULT_WAITING = 0,
    AUTHRESULT_SUCCESS = 1,
    AUTHRESULT_FAIL = 2,
    AUTHRESULT_UPDATEKEY = 3
};
```

---

_Last Updated: Based on codebase as of commit date_

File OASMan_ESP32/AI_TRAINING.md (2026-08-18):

# AI Pressure Correction — How It Works

> Full control-loop design, decision history, and tuning guide:
> [docs/pressure-goal-routine.md](docs/pressure-goal-routine.md). This file covers the ML layer.

The manifold controls bag pressure **closed-loop**: it holds a valve open and re-reads the sensor each
tick, closing when the bag reaches the goal — like height-sensor mode. The catch: **you can't read a
bag's true pressure while its valve is open.** Air flowing past the manifold-mounted sensor makes the bag
read high on fill / low on dump; the reading only settles to the truth once the valve closes.

So the learned model is a **sensor-offset corrector**:

    actualBag = rawBag + offset,   offset = f(flowDifferential)

The controller feeds the live flowing readings through `f` to recover the true pressure and stops at goal.

## The ML layer is deliberately tiny: samples → refit → predict → fade

There is **no online learner, no persisted weights, no schema/versioned model, no outlier gate, no anchor
replay**. A batch least-squares fit is ~1 ms and every sample is kept, so "train" and "keep training" are
the same operation — **re-fit** — and weights are re-derived from the samples on every boot.

| File | Role |
|---|---|
| `src/pressureMath.*` | `OffsetModel`: `computeFeatures`, `predict`, `refit` (ridge least squares) + `solveN` |
| `src/manifoldSaveData.*` | sample files on SPIFFS (`learnData`, `recordLearnSample`), the 4 RAM-only models |
| `src/airSuspensionUtil.cpp` | `refitModel`/`trainOffsetModels`, `getPredictionOffset` (fade), `getPredictedBagPressure` |
| `src/components/wheel.cpp` | closed-loop `goalRoutine`; logs samples on close (auto + manual) |
| `src/tasks/tasks.cpp` | `task_trainAI`: refit all at boot, then refit changed models every 100 ms |

There are **4 models** — up-front, up-rear, down-front, down-rear (both corners of an axle share).

**The same 4 models and 4 files serve both pressure and height-sensor mode.** In pressure mode the samples
hold psi; in height mode they hold height %. This keeps the ML layer unchanged at the cost of one rule:
stored AI data is only valid for the mode it was collected in, since mixed units train a meaningless model.
**`setheightSensorMode()` enforces this — it calls `clearPressureData()` whenever the mode actually
changes** (hand-written rather than `createSaveFuncInt` for exactly this reason; boot loads the preference
directly, so a reboot never wipes). The untrained default also follows the active mode
(`OFFSET_DEFAULT_PSI` vs `OFFSET_DEFAULT_LEVEL`).

### The model

`OffsetModel` is a 3-coefficient linear fit of the offset (psi). Features (`computeFeatures`, scaled by
100 so the squared term stays well-conditioned): `[ differential/100, (differential/100)², 1 ]`,
where differential = `rawTank − rawBag` (fill) or `rawBag` (dump). `predict` = `w·f × ML_OFFSET_NORM`.
(A prior `othersOpen`/contention feature was removed — tank sag from other open valves already shows up in
`rawTank`, which the differential captures, so it added ~0 to the fit on real data.)
The offset vanishes as flow stops (`rawBag → rawTank` on fill, `→ 0` on dump), so the estimate converges
to the truth right where the controller needs to stop; and because it's trained on
flowing-before-close → settled-after-close, it inherently absorbs the valve-close overshoot.

`refit` accumulates the normal equations over all samples, adds ridge, and solves (Gaussian elimination).
Below `ML_FIT_MIN_SAMPLES` (25) valid samples it leaves the weights alone.

### The fade / default

There is **no physics-default formula**. Before a model is trained, `getPredictionOffset` returns a flat
constant, negative on air-up and positive on air-out: `OFFSET_DEFAULT_PSI` (5) in pressure mode,
`OFFSET_DEFAULT_LEVEL` (2) in height mode. As samples accumulate it fades the trained model in:

    w = clamp((count − OFFSET_FADE_MIN) / (AI_LEARN_RATIO_NUM − OFFSET_FADE_MIN), 0, 1)
    offset = default × (1 − w) + trained × w

Below `OFFSET_FADE_MIN` (25) → pure default; at `AI_LEARN_RATIO_NUM` (150) → pure trained. When a real
trained model exists the constant is fully faded out.

### Sample collection

Every valve close logs one sample: the last **flowing** readings while the valve was open, paired with the
**settled** bag reading after close — `{ raw_bag, settled_bag, raw_tank }` (offset =
`settled_bag − raw_bag`). Two triggers, one sink (`recordLearnSample` → SPIFFS + RAM):

- **Preset / maintain moves** — `goalRoutine` logs on close (after the direction's settle time).
- **Manual moves** (BLE valveControlBittset / gamepad) — `Wheel::captureManualOffsetSample` watches this
  corner's valve state each `Wheel::loop` tick, caching the flowing readings while open and logging after
  the settle on close. Always on; only skipped while a goal routine is running (it collects its own).

Closes happen near goal, so samples concentrate where stopping accuracy matters. The
`BEGIN/END IMPORTANT DATA FOR PRO` serial dump prints every stored sample for offline analysis.

### Training

`task_trainAI` calls `trainOffsetModels()` at boot (refits all 4 from their loaded samples) then every
100 ms (refits only a model whose sample count changed). Fast conversions help: `initializeADS()` sets the
ADS1115 to `RATE_ADS1115_860SPS`.

## The closed-loop controller (`Wheel::goalRoutine`)

Decoupled into small pieces: the `goalRoutine` **coarse** loop, plus three helpers —
`waitForStableReading` (settled read), `achieveFineGoal` (**fine** phase), and `openValveForMs` (a burst).
Pressure and height mode run the **same** loop, predictor, models, fine phase and re-check. The only
per-mode differences are a `ModeTuning` struct (deadband / settle band / fine constants), the untrained
default constant, and the pressure-only bag-max ceiling.

**Coarse phase (`goalRoutine`).** Commit a direction from the true (valve-closed) reading; each tick read the
live value and compute `actual = getPredictedBagPressure(aiIndex, raw, rawTank)` (raw + learned/default
offset — psi or height % depending on mode), hold the valve open; when `actual` reaches goal, close,
rendezvous at the barrier (valve closed), then `waitForStableReading` for the true settled value, log the
flowing→settled sample, and re-decide against it (**bidirectional**: continue, reverse, or hand off to fine).

**Settled read (`waitForStableReading`).** Instead of a fixed settle wait, block until the reading holds
within a band (`SETTLE_STABLE_BAND_PSI` / `_LEVEL`) for `SETTLE_STABLE_MS` (100 ms), with a
`SETTLE_MAX_WAIT_MS` backstop. Air-out (which rises back to true slowly) waits exactly as long as it needs.

**Fine phase (`achieveFineGoal`) — runs in BOTH modes.** In pressure mode the flowing reading is a blind,
low-saturating proxy during air-out (measured: the true settled pressure scatters ±7–15 psi for a fixed
flowing reading in the mid range), so the coarse prediction cannot land precisely and tends to hunt near
goal. Height mode has no such blind spot, but it still can't stop on an exact percentage from a moving
chassis — the fine phase gives it the same precision, and it needs **no model** to do so because it works
purely off accurate valve-closed readings. Once the true reading is within the mode's `FINE_PULSE_THRESHOLD_*`
of goal, `goalRoutine` calls `achieveFineGoal`, which hones in with short **bursts** off
`waitForStableReading`. The burst starts sized to the remaining error (`clamp(err × msPerUnit, minMs, maxMs)`
from `ModeTuning`); **each time the reading crosses the goal it shrinks the burst by
`FINE_PULSE_OVERSHOOT_SHRINK`** (anti-oscillation, mirroring the old logic). It exits on: landing exactly on
goal (success); the burst shrinking below 1 ms while still crossing (hardware can't resolve finer — give up);
the reading not moving for `FINE_PULSE_MAX_TRIES` bursts (stuck: tank/bag exhausted); or the routine timeout.
Fine bursts are **not** logged (they'd pollute the model with blind near-goal samples).

**Final cross-corner re-check — runs in BOTH modes.** Corners finish at slightly different times, and a
sibling still moving can nudge an already-done corner (through the shared manifold in pressure mode, through
the chassis in height mode). After the main loop all corners rendezvous idle, then run
`FINAL_RECHECK_ROUNDS` synchronized rounds: re-read the settled value and, if off, re-correct with
`achieveFineGoal`. Each round is bracketed by a barrier so the next read happens with all corners idle again,
catching a correction that disturbed a neighbor. `getheightSensorMode()` is global, so every corner runs the
same barrier count (no club mismatch).

**Sync / safety.** `achieveFineGoal` takes no barriers (the valve is only open during a burst, never
waiting), so the never-wait-with-valve-open invariant holds and a fine corner rendezvouses only at
`goalRoutine`'s exit barrier. Pressure mode enforces the in-loop `getbagMaxPressure()` /
`MAX_PRESSURE_SAFETY` ceiling (coarse fill); height mode has no in-loop pressure ceiling. Other hard stops:
the 10 s `ROUTINE_TIMEOUT_MS`, or an `onlyAirUp` block (which accepts an overshoot rather than venting).

**Sample logging / de-dup.** A preset move closes the valve many times (each coarse close logs a
flowing→settled sample), so `recordLearnSample` drops any sample within `SAMPLE_DEDUP_PSI` of the
previous stored one for that model — killing long runs of near-identical samples while keeping distinct
pressures. The four models are independent, so an uneven up/down sample count is harmless.

## Persistence / migration

Only the **sample files** are stored (SPIFFS); weights are never persisted. One version,
`ML_SAMPLE_RECORD_VERSION` (`pressureMath.h`): if the stored `mlSampleRec` differs, `clearPressureData`
wipes the sample files (`beginSaveData`). No model/feature version — a feature change just takes effect on
the next refit.

## Tuning constants

`pressureMath.h`: `ML_OFFSET_NORM` (100), `ML_FIT_RIDGE`, `ML_FIT_MIN_SAMPLES` (25), `ML_NUM_COEFF` (3),
`ML_SAMPLE_RECORD_VERSION`. `user_defines.h`: `LEARN_SAVE_COUNT` (300), `OFFSET_DEFAULT_PSI` (5),
`OFFSET_FADE_MIN` (25), `AI_LEARN_RATIO_NUM` (150), `SAMPLE_DEDUP_PSI` (1), `FINAL_RECHECK_ROUNDS` (4),
`SETTLE_STABLE_MS` (100), `SETTLE_MAX_WAIT_MS` (1500), `FINE_PULSE_OVERSHOOT_SHRINK` (0.5),
`FINE_PULSE_MAX_TRIES` (8). `OFFSET_SAMPLE_SETTLE_MS`/`_DOWN_MS` are now only for the manual-move capture.

The control loop's mode-specific knobs come in pairs — pick the one for the mode you're tuning:

| | Pressure mode | Height mode |
|---|---|---|
| deadband | `PRESSURE_DEADBAND_PSI` (0) | `LEVEL_DEADBAND_PERCENTAGE` (0) |
| settle band | `SETTLE_STABLE_BAND_PSI` (1) | `SETTLE_STABLE_BAND_LEVEL` (1) |
| fine threshold | `FINE_PULSE_THRESHOLD_PSI` (5) | `FINE_PULSE_THRESHOLD_LEVEL` (5) |
| fine ms per unit | `FINE_PULSE_MS_PER_PSI` (5) | `FINE_PULSE_MS_PER_LEVEL` (20) |
| fine burst min/max | `FINE_PULSE_MIN_MS` (5) / `FINE_PULSE_MAX_MS` (100) | `FINE_PULSE_MIN_MS_LEVEL` (5) / `FINE_PULSE_MAX_MS_LEVEL` (150) |

The finest achievable step is governed by the mode's `FINE_PULSE_MIN_MS*` together with
`FINE_PULSE_OVERSHOOT_SHRINK`. With a 0 deadband the settle band must stay tight, or a "settled" reading can
wobble wider than the controller will accept and it hunts.

## Future improvements

- **Better features for height mode.** In height mode the model learns valve-close *overshoot* (the level
  sensor already reads true during flow), but it currently reuses the pressure feature — the tank/bag
  differential — because that keeps the sample layout and `pressureMath` untouched. The physically causal
  input is the **measured rate of travel** at the moment of reading, since overshoot is displacement after
  the read (`≈ velocity × lag`). Worth revisiting if height accuracy plateaus; it would need a rate tracker
  and a per-mode feature branch.
- **Separate storage per mode.** Today both modes share the same 4 files, so switching modes wipes the
  training data. A second file set would remove that at the cost of ~3.6 KB heap and a wider model index.
- Average the flowing reading over the last few pre-close ticks to denoise the model feature.
- The manual-move capture still uses fixed `OFFSET_SAMPLE_SETTLE_*` waits rather than `waitForStableReading`.

Note: `eval/model_eval.cpp` targeted the old online-learning model and is stale until ported.

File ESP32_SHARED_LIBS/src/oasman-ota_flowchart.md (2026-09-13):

# oasman-ota OTA flow

ESP32 [`directdownload.cpp`](./directdownload.cpp) calls one URL:

`https://oasman-ota.gopro2027.workers.dev/?firmware=<name>&tag=<installed-tag>` (plain `http://` only for a one-time insecure update the user opts into)

Implementation: [`oasman-ota_worker.js`](./oasman-ota_worker.js)

---

## Flowchart (recommended in VS Code preview)

```mermaid
flowchart TB
    subgraph esp32 [ESP32]
        A[downloadUpdate connects WiFi]
        B[installFirmware single GET]
        C[Update.writeStream, verify MD5, restart]
        V{Runs OTA_VERIFY_CONFIRM_MS without rebooting?}
        OK[esp_ota_mark_app_valid_cancel_rollback]
        RB[Bootloader boots the previous slot]
    end

    subgraph worker [oasman-ota Worker]
        D[Validate firmware + tag params]
        E{Release JSON cache valid?}
        F[Fetch releases list from GitHub API]
        G[Cache JSON 30 min]
        M[Pick newest release that ships this firmware]
        H{Installed tag equals that release tag?}
        I{Firmware binary cache valid?}
        J[Fetch firmware.bin from GitHub]
        K[Cache binary 30 min]
        L[Clear old binaries if tag changed]
    end

    subgraph github [GitHub]
        API[(API releases list)]
        BIN[(releases/download asset)]
    end

    A --> B
    B --> D
    D --> E
    E -->|yes| M
    E -->|no| F
    F --> API
    API --> G
    G --> L
    L --> M
    M --> H
    H -->|yes| R204["204 No Content"]
    H -->|no| I
    I -->|yes| R200["200 firmware bytes"]
    I -->|no| J
    J --> BIN
    BIN --> K
    K --> R200
    R204 --> ESP204[Set ALREADY_UP_TO_DATE]
    R200 --> C
    C --> V
    V -->|yes| OK
    V -->|no| RB
```

The new image boots unconfirmed (`ESP_OTA_IMG_PENDING_VERIFY`) and is confirmed once `loop()` has
run for `OTA_VERIFY_CONFIRM_MS` -- see [`otarollback.cpp`](./otarollback.cpp). Any reboot before
that point is reverted by the bootloader.

---

## Sequence diagram (same flow, chat-style)

```mermaid
sequenceDiagram
    autonumber
    participant ESP as ESP32
    participant OTA as oasman-ota
    participant GH as GitHub

    ESP->>OTA: GET with firmware and tag
    OTA->>GH: GET releases list
    Note right of OTA: JSON cached 30 minutes

    OTA->>OTA: Pick newest release with e.g. manifold_v4_firmware.bin

    alt Installed tag equals that release tag
        OTA-->>ESP: 204 No Content
        Note left of ESP: UPDATE_STATUS_FAIL_ALREADY_UP_TO_DATE
    else Newer release available
        OTA->>GH: GET firmware binary URL
        Note right of OTA: Verified against GitHub sha256, cached 30 minutes per file
        OTA-->>ESP: 200 octet-stream, Content-Length, X-Firmware-MD5
        Note left of ESP: Update.begin, setMD5, writeStream
        alt MD5 matches
            Note left of ESP: Boot partition switched, reboot unconfirmed
        else MD5 mismatch
            Note left of ESP: Boot partition untouched, retry then FAIL_CORRUPT_DOWNLOAD
        end
    end
```

---

## Plain-text summary

| Step | Who | What |
|---|-----|---|
| 1 | ESP32 | `GET oasman-ota?firmware=...&tag=...` |
| 2 | Worker | Load or fetch `releases` list (30 min cache; authenticated with `GITHUB_TOKEN` if set) |
| 3 | Worker | If newest GitHub tag changed since last cache, delete old `*_firmware.bin` caches |
| 4 | Worker | Pick the newest release that actually ships `{firmware}_firmware.bin` |
| 5 | Worker | If `tag` param equals that release's `tag_name` → **204** (already up to date) |
| 6 | Worker | Else fetch `{firmware}_firmware.bin` (cache or GitHub), check it against the asset's GitHub `sha256` digest (**502** on mismatch), serve → **200** |
| 7 | Worker | Set `X-Firmware-MD5`, computed once when the file is downloaded and stored with the cached copy |
| 8 | ESP32 | Flash via `Update` API, reject the image if the MD5 does not match, then restart |
| 9 | ESP32 | New image boots `PENDING_VERIFY`; confirmed after `OTA_VERIFY_CONFIRM_MS` of `loop()`, reverted if it reboots first |

## Failure modes and what catches them

| What goes wrong | Caught by | Result |
|---|---|---|
| Worker's copy from GitHub corrupted | Worker checks it against the asset's GitHub `sha256` | **502**, never cached; device retries and the worker refetches |
| Transfer truncated | `written != fileSize` | Retry; running firmware untouched |
| Cached copy or body corrupted after the worker verified it | `Update.setMD5` against `X-Firmware-MD5` | Retry, then `FAIL_CORRUPT_DOWNLOAD`; boot partition never switched |
| Image corrupt past the MD5 (e.g. bad flash write) | Bootloader image verification | Boots the other slot |
| Image can't boot (crash / boot loop in setup or early tasks) | Bootloader sees `PENDING_VERIFY` on the reboot | Boots the previous slot |
| Image hangs before it is confirmed | Bootloader, on the next reboot or power cycle | Boots the previous slot |
| Image boots but misbehaves | Not covered -- releases are tested before publishing | Stays installed |

Every GitHub request that fails to connect or returns a non-2xx status is logged with `console.error` as
`GitHub <request> rejected: HTTP <status> ...`, so it shows up in the worker's Cloudflare logs.

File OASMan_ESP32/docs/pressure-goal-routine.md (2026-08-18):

# Pressure Goal / Presets — Design & Rationale

How OAS-Man drives each corner to a target pressure (or height) when a preset is loaded, why the
control loop is shaped the way it is, and the measured data behind every design decision. This is the
reference for future improvements to this code.

Companion docs:

- **[AI_TRAINING.md](../AI_TRAINING.md)** — the offset-model learning layer (samples → refit → predict → fade).
- **[docs/goal-sync-barrier.md](goal-sync-barrier.md)** — the `goalSync*` thread-rendezvous mechanism.

Code lives in `src/components/wheel.cpp` (`goalRoutine`, `achieveFineGoal`, `waitForStableReading`,
`openValveForMs`, `initPressureGoal`) with the model layer in `src/pressureMath.*`,
`src/airSuspensionUtil.cpp` (predictors, refit), and `src/manifoldSaveData.cpp` (sample storage).
Tunables in `ESP32_SHARED_LIBS/src/user_defines.h`.

---

## 1. The core problem: you cannot read a bag's pressure while its valve is open

Each corner has one pressure sensor plumbed where air flows between the tank and the bag. While a
valve is open, air rushing past the sensor skews the reading (Bernoulli/flow effects):

- **Filling (air-up):** the sensor reads **high** — it sees tank-side pressure bleeding through.
- **Venting (air-out):** the sensor reads **low** — it sees the pressure collapsing toward atmosphere.

Only after the valve closes and the air settles does the reading converge to the truth.

Measured on the Corvette (offset = settled − flowing, at the moment of valve close):

| Direction | Typical offset | Predictability |
|---|---|---|
| Air-up | ≈ −6 to −10 psi | Good — model RMSE ≈ 2.5–3 psi |
| Air-out | ≈ +15 to +20 psi | Poor — model RMSE ≈ 4.5–6 psi |

Worse, air-out has a measured **blind spot**: the flowing reading saturates toward a low plateau that
barely depends on true bag pressure. Holding the flowing reading fixed at ~15–30 psi mid-vent, the
*true* settled pressure ranged **25→59 psi (std ≈ 7–9 psi)**. That information is simply not in the
sensor during venting — no model or feature can recover it. This single fact drives most of the
design: the flowing reading is good enough to *move fast toward* goal, but only the **valve-closed
settled reading** can be trusted to *land* on goal.

---

## 2. Control flow overview

```
Load preset → initPressureGoal(target) per corner → flag set → wheel task runs goalRoutine:

  ┌─ COARSE loop ──────────────────────────────────────────────────────────┐
  │ read true (valve-closed) value                                         │
  │   at goal?            → done                                           │
  │   within 5 psi?       → achieveFineGoal() → done                       │
  │   else commit dir, hold valve open, stop when PREDICTED value = goal,  │
  │   close, barrier-rendezvous, settle-to-stable, log sample, re-decide   │
  └────────────────────────────────────────────────────────────────────────┘
  then: all corners rendezvous idle
  ┌─ FINAL RE-CHECK (×FINAL_RECHECK_ROUNDS) ──────────────────────────────┐
  │ settle-to-stable read → off goal? achieveFineGoal() → barrier         │
  └────────────────────────────────────────────────────────────────────────┘
```

### 2.1 Entry — `initPressureGoal(newPressure, onlyAirUp, onComplete)`

- Rejects a goal above `getbagMaxPressure()` (pressure mode) or ~103% of `getHeightSensorMax()`.
- Pressure mode: refuses to start an air-up the tank can't deliver (tank pressure below current bag).
- Sets `pressureGoal`, `routineStartTime`, and the per-corner start flag; the four wheel FreeRTOS
  tasks each pick it up in `Wheel::loop()` → `goalRoutine()`.
- `onlyAirUp` (used by maintain-pressure) forbids venting anywhere in the routine — an overshoot is
  accepted rather than corrected downward.

### 2.2 Coarse phase (`goalRoutine`)

**Pressure and height mode run the same loop, predictor, models, fine phase and re-check.** The per-mode
differences are narrow: a `ModeTuning` struct (deadband / settle band / fine constants), the untrained
default constant, and the pressure-only bag-max ceiling.

```cpp
double actual = getPredictedBagPressure(aiIndex, raw, rawTank); // raw + learned/default offset
```

**Both modes share the same 4 models and files** — the samples just hold height % instead of psi while in
height mode. That keeps the ML layer untouched, at the cost of one rule: the AI data must be cleared when
switching modes, since mixed units train a meaningless model. `setheightSensorMode()` does this
automatically on an actual mode change. Note the two modes are learning different
physics: pressure mode corrects a flow-skewed sensor, height mode corrects valve-close overshoot (the
level sensor already reads true during flow). See §6 for the feature caveat that follows from this.

Cycle: with the valve closed the reading is true, so decide there — finish (within deadband), hand
off to fine (within the mode's fine threshold), or commit a direction. Then hold the valve open,
re-computing `actual` from the live reading each ~1 ms tick, and close when `actual` reaches goal.
After closing: rendezvous at the barrier (valve closed), `waitForStableReading` for the true settled
value, log the flowing→settled sample, drop the committed direction, and re-decide.

The re-decide is **bidirectional** — it continues, reverses, or hands off to fine based on the true
settled reading. (Earlier versions only corrected undershoot and accepted overshoot; the data showed
air-out overshoots low half the time, so monotonic verify systematically landed low.)

Both deadbands are **0** (exact value), which is safe only because the fine phase exists.

### 2.3 Settled read — `waitForStableReading(band)`

Every "true" reading uses this instead of a fixed wait: block until the reading holds within `band`
(`SETTLE_STABLE_BAND_PSI` 1 / `SETTLE_STABLE_BAND_LEVEL` 1) for `SETTLE_STABLE_MS` (100 ms), with a
`SETTLE_MAX_WAIT_MS` (1500 ms) backstop. Air-out settles much slower than air-up (the bag reading has
to *rise* ~15–20 psi back to truth after venting), so a stability gate waits exactly as long as
physically needed — fixed waits were either too short for air-out (corrupting both verify reads and
training labels) or wastefully long for air-up.

### 2.4 Fine phase — `achieveFineGoal()` (both modes)

The coarse prediction cannot land precisely near goal — in pressure mode because of the §1 blind spot
(it stops early, creeps in small steps, or oscillates), in height mode because you can't stop a moving
chassis on an exact percentage from a live reading. So within the mode's fine threshold (5 psi / 5 %),
stop trusting the live prediction entirely and hone in on the **true** reading with short bursts:

1. `waitForStableReading` → error = goal − true. Within deadband → success, return.
2. Burst length: starts at `clamp(err × msPerUnit, minMs, maxMs)` from the mode's `ModeTuning`.
3. **Anti-oscillation:** each time the reading *crosses* the goal (direction flips), the burst is
   multiplied by `FINE_PULSE_OVERSHOOT_SHRINK` (0.5). Successive approximation: bursts shrink until
   it lands exactly, or the burst falls below 1 ms (hardware can't resolve finer — give up).
4. **Stuck detector:** if the reading doesn't move at all for `FINE_PULSE_MAX_TRIES` (8) bursts
   (tank/bag exhausted), give up rather than pulse until the routine timeout.
5. `onlyAirUp` + need-to-vent → accept where we are. Routine timeout also exits.

This mirrors the pre-ML main-branch anti-oscillation logic (shrink valve time on each goal crossing).
Note it needs **no learned model** — it only ever reads settled, valve-closed values, so it delivers the
same precision in both modes regardless of how well trained the model is.

The finest achievable step is governed by the mode's `FINE_PULSE_MIN_MS*` together with the shrink
factor; those two are the knobs for "lands exactly."

### 2.5 Final cross-corner re-check

Observed on-car: a corner that finishes early can be nudged a few units off by a sibling corner still
correcting (shared manifold/tank coupling in pressure mode, chassis coupling in height mode — and a
sibling's motion can also disturb the early corner's "stable" reading). So after **all** corners
rendezvous idle, every corner runs
`FINAL_RECHECK_ROUNDS` (4) synchronized rounds: settle-to-stable read → if off goal,
`achieveFineGoal()` → close valves → barrier. The per-round barrier means each round's *read* happens
with all corners idle (clean), and a round-N correction that disturbed a neighbor gets caught in
round N+1.

Chosen deliberately as the **simple concurrent** design. Its known residual: corrections in the very
last round are never themselves re-verified, so a tiny leftover can survive (that's why the round
count was raised 2→4). The robust alternative, if ever needed: loop **until a round makes zero
corrections** (capped), or re-check corners **sequentially** (one corrects while three hold still) —
sequential fully eliminates mutual disturbance at the cost of complexity/time.

Both modes run the re-check. `heightSensorMode` is global, so all corners run the same barrier count
regardless of mode — no club mismatch.

### 2.6 Thread sync (summary — see goal-sync-barrier.md)

Four wheel tasks, one dynamic "club" (`goalSyncJoin/Leave/Barrier`). **INVARIANT: a corner only ever
waits at a barrier with its valves closed** — a flowing corner simply hasn't reached the barrier call
yet, so a waiting corner is always harmless no matter how long it waits. `achieveFineGoal` takes no
barriers at all (bursts are quick and local); a fine corner rendezvouses at the exit/re-check
barriers only. The barrier timeout (6000 ms) is a backstop, sized above the longest single fill.

### 2.7 Safety

- **In-loop ceiling (coarse fill, pressure mode):** close + abort immediately if the predicted value
  reaches `getbagMaxPressure()` (≤ `MAX_PRESSURE_SAFETY` 200). No settle/verify on this path.
- **`ROUTINE_TIMEOUT_MS` (10 s):** bounds the whole routine (empty tank, stuck sensor, hunting).
- **Exit path always closes both valves** before the final rendezvous.
- Known gap (accepted for now): height mode has no in-loop bag-pressure ceiling while chasing a
  height target (TODO in code).

---

## 3. The learning layer (summary — see AI_TRAINING.md for full detail)

`actualBag = rawBag + offset`, `offset = f(flowDifferential)` — a per-axle-per-direction 3-coefficient
linear model (`[d, d², 1]`, d = differential/100; differential = tank−bag on fill, bag on dump), fit
by closed-form ridge least squares over all stored samples (~1 ms), re-fit from scratch whenever the
sample count changes. **Nothing is persisted but the samples** (SPIFFS, 4 files); weights re-derive
every boot; one schema version (`ML_SAMPLE_RECORD_VERSION`) whose mismatch wipes samples.

Before training data exists, the offset is a flat constant (−5 fill / +5 dump, `OFFSET_DEFAULT_PSI`),
faded linearly into the trained model between `OFFSET_FADE_MIN` (25) and `AI_LEARN_RATIO_NUM` (150)
samples.

**Sample collection:** every *coarse* close logs `{flowing bag, settled bag, flowing tank}` (the
settled label comes from the stability-gated read). Manual up/down moves also always log (via
`captureManualOffsetSample`, which is skipped while a goal routine runs and in height mode — there is
no on/off flag for it). **Fine bursts are deliberately NOT logged** — near-goal air-out samples
are exactly the blind-spot data (±9 psi label scatter) that poisons the fit. `SAMPLE_DEDUP_PSI` (1)
drops a sample within 1 psi (flowing AND settled) of the previous stored one, killing the long
runs of near-identical samples a single preset move produces (measured: up to 18 in a row, 15–25% of
the file). The four models are independent, so uneven up/down counts are harmless.

**`othersOpen` was removed as a feature:** tank sag from other open valves already shows up in
`rawTank` (which the differential captures); measured contribution ≈ 0. Contention needs no separate
input.

---

## 4. Design history — what was tried, what the data said

Understanding *why* the current shape won matters for future changes:

1. **Valve-time prediction (rejected).** The original ML predicted *how long* to open the valve from
   (start, goal, tank). It failed for structural reasons: open-loop (no mid-move correction), a
   self-reinforcing data-poisoning loop (its own bad moves generated its training data), and poor
   extrapolation across pressure ranges. Accuracy requirement (±3 psi) was unreachable.
2. **Closed-loop on the raw flowing reading (rejected).** Mirrors the height-sensor branch, but the
   raw reading is wrong by the §1 offsets — stops ~10 psi early on fill, ~20 late on dump.
3. **Closed-loop on a learned offset correction (current coarse phase).** Turns the ML from "predict
   the future" into "correct a sensor" — a far easier, self-labelling problem (every valve close
   yields a perfect training pair automatically).
4. **Verify-after-close** (monotonic → **bidirectional**): the settled reading is re-checked and the
   loop continues/reverses. Monotonic verify accepted overshoot and biased air-out low → made
   bidirectional.
5. **Deadband journey 2 → 1 → 0:** 2 left ±2 psi errors; 0 alone caused hunting (valves overshoot the
   exact integer between ticks — a tick can move 1–3 psi); 1 was a stopgap. The **fine-pulse phase**
   is what made 0 viable.
6. **Fine pulse + anti-oscillation crossing-shrink** (§2.4): resolves finer than a normal control
   tick; immune to the blind spot because it reads valve-closed only.
7. **Final concurrent re-check** (§2.5): fixes the cross-corner nudge; simple-concurrent chosen over
   sequential, rounds raised 2→4 from on-car results.
8. **Height mode joined the same loop** (user testing): it was landing imprecisely because it skipped
   the fine phase and the re-check. Both now run in height mode. A learned model for height was
   prototyped and **deliberately dropped** — the level sensor already reads true during flow, so the
   only thing left to learn is a small valve-close overshoot, which the fine phase corrects anyway
   without the cost of a second sample store, feature set and file set.

---

## 5. Tuning guide

All in `user_defines.h`. Control-loop knobs come in pressure/height pairs (`*_PSI` / `*_LEVEL`) — pick the
one for the mode you're tuning. The learning knobs are pressure-only.

| Symptom | Knob(s) |
|---|---|
| Lands 1–2 units off, load-preset-again fixes it | `FINAL_RECHECK_ROUNDS` up (or implement loop-until-clean, §2.5) |
| Fine phase nudges past exact repeatedly | `FINE_PULSE_MIN_MS`/`_LEVEL` down (finest step), `FINE_PULSE_OVERSHOOT_SHRINK` toward 0.5–0.7 |
| Fine phase too slow / too many bursts | `FINE_PULSE_MS_PER_PSI` / `_PER_LEVEL` up (aim: one burst ≈ half the gap) |
| Coarse hands off too early/late | `FINE_PULSE_THRESHOLD_PSI` / `_LEVEL` |
| Hunting near goal (never settles) | settle band (`SETTLE_STABLE_BAND_*`) must be tight for the 0 deadband; else raise that mode's deadband |
| Verify reads look wrong on air-out | `SETTLE_STABLE_MS` up / `SETTLE_STABLE_BAND_PSI` down (`SETTLE_MAX_WAIT_MS` is the ceiling) |
| Samples accumulate too slowly | `SAMPLE_DEDUP_PSI` down (min 0 = off) |
| Model trusted too soon/late | `OFFSET_FADE_MIN`, `AI_LEARN_RATIO_NUM` |
| Untrained behavior off | `OFFSET_DEFAULT_PSI` (flat ±psi before training) |

Bench/serial diagnostics: the boot `BEGIN/END IMPORTANT DATA FOR PRO` dump prints every stored sample
(3-tuples) for offline analysis; `Refit model N: ...` lines show live weights; `task_trainAI` prints
its stack high-water mark at boot.

---

## 6. Known limitations & future improvements

- **Last-round re-check residual** (§2.5) — replace fixed rounds with loop-until-no-corrections, or
  sequential per-corner re-check.
- **Air-out blind spot is physical** — no feature will fix it; only the fine phase / settled reads
  address it. Don't spend effort on fancier flowing-reading models for dump.
- **Height mode reuses the pressure feature.** In height mode the model learns valve-close overshoot, but
  its input is still the tank/bag differential (chosen to keep the sample layout and `pressureMath`
  untouched). The physically causal input is the **measured rate of travel** at the read, since overshoot
  is displacement after the read (`≈ velocity × lag`). Expect the bias term to do most of the work in
  height mode — worth revisiting only if height accuracy plateaus.
- **Shared files between modes** — switching modes wipes the AI data (mixed units train a meaningless
  model), so a user who moves between modes keeps restarting training. A second file set would remove
  that rule (~3.6 KB heap).
- **Height mode in-loop pressure ceiling** — TODO in `goalRoutine`; heavy load or a stuck level
  sensor could over-pressure a bag while chasing height.
- **Manual-move capture** still uses fixed settle waits (`OFFSET_SAMPLE_SETTLE_MS`/`_DOWN_MS`) rather
  than `waitForStableReading`.
- **Flowing-feature denoise** — average the last few pre-close ticks instead of one instantaneous
  reading.
- `eval/model_eval.cpp` targets the deleted online-learning model; stale until ported.

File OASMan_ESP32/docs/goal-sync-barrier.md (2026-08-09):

# Wheel goal-routine thread synchronization

How the four wheel tasks stay in step while airing to a target, defined in
[`OASMan_ESP32/src/components/wheel.cpp`](../src/components/wheel.cpp).

## Why this exists

Each corner runs `Wheel::goalRoutine()` on its **own FreeRTOS task** (four tasks,
created in [`tasks.cpp`](../src/tasks/tasks.cpp): `task_wheel` → `Wheel::loop()` →
`goalRoutine()`). Every routine independently drives its IN/OUT solenoid toward a
pressure/height target. Without coordination the corners finish and re-evaluate at
unrelated times, so the car moves unevenly and the solenoids fire raggedly.

The goal-sync barrier couples the **active** wheels: a corner that reaches its target
early waits for the slower corners before the routine ends, so the group starts together
and finishes together.

## The control model it runs on top of

`goalRoutine()` is **closed-loop / continuous-flow**, not pulse-based:

- It commits a direction from the true (valve-closed) reading, opens the valve, and
  **leaves it open across iterations**, running each live (flowing) reading through a
  predictor to recover the true bag value.
- The valve **closes once the predicted value reaches goal**, then a non-blocking
  *settle* window elapses and the settled value is re-verified (correcting over/undershoot).
- Each loop iteration is short (~1 ms `delay(1)` plus the ADC reads) in both pressure and
  height mode.

So during a move the valve is **open** for the whole fill/dump and **closed** during
settle and after completion.

## The primitive

Three functions over three shared, mutex-protected counters (`goalSyncClubSize`,
`goalSyncWaiting`, `goalSyncGeneration`; all access is inside
`wheelThreadLock()`/`wheelThreadUnlock()`, a 1-tick spin-with-yield mutex).

The set of wheels currently participating is the **club**. A wheel joins when it starts
its routine and leaves when it finishes, so the barrier automatically targets only the
corners that actually need to move.

### `goalSyncJoin()`
Called once at the top of `goalRoutine()`. Increments `goalSyncClubSize`. The wheel is
now a club member and everyone else's barrier will wait for it.

### `goalSyncLeave()`
Called once at the very end of `goalRoutine()`. Decrements `goalSyncClubSize`, then — if
wheels are already waiting and the reduced club size is now satisfied
(`goalSyncWaiting >= goalSyncClubSize`, or the club is empty) — releases them by bumping
`goalSyncGeneration`. This prevents a wheel that finishes early from stranding the others
at a count that can never be reached.

### `goalSyncBarrier(timeoutMs)`
A sense-reversing (generation-based) barrier:

1. Capture the current `goalSyncGeneration`, increment `goalSyncWaiting`.
2. If this wheel is the last to arrive (`goalSyncWaiting >= goalSyncClubSize`), reset
   `goalSyncWaiting`, bump `goalSyncGeneration`, and return immediately — releasing everyone.
3. Otherwise spin (`delay(1)`) until **any** of: the generation changed (someone released
   the group), the club fully gathered, the club emptied, or `timeoutMs` elapsed (backstop).

Using the captured generation to detect release makes the barrier safe against a fast
wheel "lapping" a slow one; `goalSyncWaiting` is always reset to 0 by whoever triggers a
release, so counts never go stale.

## The invariant: only ever wait at the barrier with the valve CLOSED

This is the load-bearing rule that keeps the barrier safe on a real vehicle. **A wheel
must never block at the barrier while its valve is open** — otherwise the wait would keep
airing that corner while its `reached`/`overCeiling` checks are not running, risking
overshoot for up to the full timeout.

`goalRoutine()` enforces it with exactly two barrier call sites, both at points where the
valve is *provably* closed:

1. **In-loop rendezvous is placed immediately after `valve->close()`** in the target-reached
   path (right after `settleUntil` is armed). A corner that is still flowing has not reached
   this line, so it never blocks the group with a valve open; a corner that just closed after
   reaching target blocks here until every other active corner has also closed. (An earlier
   revision inferred valve state from a per-tick `valveOpenThisTick` flag and put the barrier
   at the end of the loop; that was replaced because tying it directly to the close event is
   unambiguous — no flag, and no six-valve edge case where a valve left open by a prior tick
   could reach an end-of-loop barrier.)
2. **Valves are closed before the exit rendezvous.** Both solenoids are closed *before* the
   final `goalSyncBarrier()` / `goalSyncLeave()`, covering the routine-timeout break that can
   fire mid-fill.

Both sites feed the same global barrier counters, so a corner sitting at the in-loop
rendezvous and a corner at the exit rendezvous still gather each other — placement never
causes a deadlock.

Consequence, using a 4500 ms corner and a 100 ms corner as the example: the 100 ms corner
reaches target, closes, and blocks at the barrier — **valve closed, so harmless** — until
the 4500 ms corner also closes and arrives. They then release together and finish
together. The wait is bounded by the timeout below.

## The timeout

A single, mode-independent cap:

| Constant | Value |
|---|---|
| `GOAL_SYNC_BARRIER_TIMEOUT_MS` | **6000 ms** |

Because of the invariant, every barrier wait happens with the valve closed, so the cap
can be as generous as needed with no airing risk. It must exceed the longest a slow corner
can stay open before it closes and reaches the barrier — a single fill can run up to
~5000 ms — so 6000 ms lets a fast corner wait for the slowest before the rendezvous, and
only fires on a genuine stall (the routine itself is independently capped at
`ROUTINE_TIMEOUT_MS` = 10 s).

> History: an earlier revision used a split 6000 ms (pressure) / 100 ms (height) cap,
> reasoned from the *old* pulse-based routine where height mode waited at the barrier with
> the valve open. Once the routine became flow-based and the never-wait-with-valve-open
> invariant was enforced for both modes, the short height cap was no longer needed and the
> two collapsed into one constant.

## Invariants (why it can't deadlock or leak)

- **Every `goalSyncJoin()` is matched by exactly one `goalSyncLeave()`.** All `break`
  paths out of the loop fall through to the final barrier + leave, and the start flag is
  only cleared after leaving. Club membership can't leak.
- **No permanent stall.** Normal release comes from the club gathering or a wheel leaving;
  the timeout guarantees forward progress even if a wheel is starved.
- **No wait with an open valve** (see the invariant above), so a fired timeout is never a
  safety event — it just lets the waiting (idle, closed) corners proceed.
- **No nested locking.** Join/Leave/Barrier each take and release the mutex in balanced,
  non-nested pairs.

## Known residual looseness

- **First iteration isn't tightly aligned.** The four wheel tasks poll on independent
  `delay(100)` cycles and pick up their start flags (set sequentially from the BLE task)
  up to ~100 ms apart, so the initial valve opens are staggered.
- **During the flow itself the corners run independently** (each to its own target); the
  barrier couples the *start* and the *completion*, not the moment-to-moment airflow.

## Verifying on-device

Build and flash the relevant env (e.g. `manifold_v4_dev`), then listen: corners should
finish and settle together during a preset change rather than one wrapping up long before
the rest. For hard data, temporarily log `thisWheelNum`, `millis() - startMs`, and whether
the barrier exited via generation-change vs. timeout inside `goalSyncBarrier()`; the
timeout branch should be rare, and when it fires the valve is always already closed.

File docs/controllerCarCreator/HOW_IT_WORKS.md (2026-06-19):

# How the OAS-Man Car Editor Works

This document explains the web-based car image editor in `docs/controllerCarCreator/`: what problem it solves, how it is built, how the editing workflow runs in the browser, and how exported LVGL C files plug into the Wireless Controller firmware.

For quick build/run instructions, see [README.md](./README.md).

---

## Purpose

The OAS-Man Wireless Controller shows a stylized car and wheels on the presets screen. Builders can replace those graphics with a photo of their own vehicle so the UI feels personalized.

The original workflow used a Python Tkinter desktop tool:

`Wireless_Controller/tools/imageCreator/car_creator.py`

That tool let you outline wheels and body from a photo, align them over device-specific reference images, and export PNGs. You then had to run those PNGs through [lvgl.io/tools/imageconverter](https://lvgl.io/tools/imageconverter) to get `.c` files for the firmware.

The web editor replaces that two-step export with a browser workflow that can either:

- **Upload RGB565A8 bytes over USB serial** directly to the controller (recommended), or
- Download ready-to-compile LVGL sources (`img_car_custom.c`, `img_wheels_custom.c`) for compile-time use

Those formats match the preset assets under `Wireless_Controller/device_libs/<device>/images/presets/` (for example `img_car.c`, `img_wheels.c`).

---

## USB serial upload (primary workflow)

The editor uses the **Web Serial API** (same browser capability as the Device Console on [oasman.dev/flash](https://oasman.dev/flash)) — not ESP Web Tools / esptool, which only flash full firmware images.

```mermaid
sequenceDiagram
    participant Browser as CarEditor
    participant FW as ControllerFirmware
    participant FS as LittleFS

    Browser->>FW: CAR_BEGIN w h size
    Browser->>FW: RGB565A8 bytes
    FW->>FS: /custom/car.bin
    FW-->>Browser: CAR_OK
    Browser->>FW: WHEELS_BEGIN w h size
    Browser->>FW: RGB565A8 bytes
    FW->>FS: /custom/wheels.bin
    FW-->>Browser: WHEELS_OK
    Browser->>FW: DONE
    FW-->>Browser: DONE
    FW->>FW: ESP.restart
```

### Controller-side storage

Firmware modules:

- `Wireless_Controller/src/custom_car_storage.cpp` — mounts LittleFS, loads/saves `/custom/car.bin` and `/custom/wheels.bin` with a 16-byte `OASC` header + RGB565A8 payload into PSRAM-backed `lv_image_dsc_t` structs.
- `Wireless_Controller/src/serial_image_upload.cpp` — upload-mode serial protocol handler.

On normal boot, `customCarStorageInit()` runs after `beginSaveData()`. If valid custom files exist, `getPresetCarImage()` / `getPresetWheelsImage()` in `ui_scrPresets.cpp` return the runtime images instead of device-lib defaults.

Upload mode is entered via **Settings → Upload custom car (USB)**, which sets an NVS flag (`carUploadMode`) and reboots. On that boot, normal UI/BLE is skipped; the device prints `OASMAN_IMG_READY` and waits up to 10 minutes for the web tool.

### Serial protocol

| Line (host → device) | Meaning |
| --- | --- |
| `CAR_BEGIN {w} {h} {size}` | Start car binary transfer (`size = w×h×3`) |
| *(raw bytes)* | RGB565A8 payload |
| `WHEELS_BEGIN {w} {h} {size}` | Start wheels binary transfer |
| *(raw bytes)* | RGB565A8 payload |
| `DONE` | Commit and reboot |

| Line (device → host) | Meaning |
| --- | --- |
| `OASMAN_IMG_READY` | Upload mode active |
| `CAR_OK` / `WHEELS_OK` | Image saved to LittleFS |
| `DONE` | Success; device reboots |
| `ERR {message}` | Failure; retry allowed |

---

## High-level architecture

The app follows the same pattern as `docs/flash/`: source files are compiled into one standalone `index.html` that runs without a web server.

```
┌─────────────────┐
│    app.tsx      │  React UI + canvas image logic + LVGL C export
└────────┬────────┘
         │
┌────────┴────────┐     ┌──────────────────────────────────────────┐
│  template.html  │     │  Wireless_Controller/device_libs/        │
│  (HTML + CSS)   │     │    <device>/images/presets/img_car.png   │
└────────┬────────┘     │    <device>/images/presets/img_wheels.png│
         │              └──────────────────┬───────────────────────┘
         │                                 │
         └──────────────┬──────────────────┘
                        │
                 ┌──────▼──────┐
                 │  build.mjs  │  esbuild transform + preset embed
                 └──────┬──────┘
                        │
                 ┌──────▼──────┐
                 │ index.html  │  Single file, open in Chrome/Edge
                 └─────────────┘
```

At runtime:

1. React and ReactDOM load from CDN `<script>` tags (UMD globals).
2. `window.PRESET_IMAGES` holds base64 data URLs and dimensions for each supported controller.
3. The inlined app mounts on `#root` and never talks to a backend.

---

## Build pipeline (`build.mjs`)

### Step 1 — Transpile `app.tsx`

`esbuild.transform()` compiles TypeScript/JSX to minified ES2019 JavaScript. React is **not** bundled; `app.tsx` declares `React` and `ReactDOM` as globals, matching `template.html`.

### Step 2 — Embed device presets

`loadPresets()` scans `Wireless_Controller/device_libs/` for subdirectories. For each device it tries to read:

- `images/presets/img_car.png`
- `images/presets/img_wheels.png`

If both exist, they are:

1. Base64-encoded into `data:image/png;base64,...` strings.
2. Measured with a lightweight PNG header parse (`pngDimensions()` reads width/height from bytes 16–23).

Devices without both PNGs are skipped (for example `ws1p8knob`, which has no circular-display car presets).

The result is injected at the `/* __PRESETS__ */` placeholder:

```javascript
window.PRESET_IMAGES = {
  ws2p8: {
    name: '2.8" Waveshare',
    car: 'data:image/png;base64,...',
    carW: 240,
    carH: 79,
    wheels: 'data:image/png;base64,...',
    wheelsW: 240,
    wheelsH: 53
  },
  // ws2p8b, ws3p5, ws3p5b, ...
};
```

Human-readable names come from a fixed map in `build.mjs`; unknown folder names fall back to the folder id.

### Step 3 — Write `index.html`

`template.html` placeholders are replaced:

| Placeholder | Replaced with |
| --- | --- |
| `/* __PRESETS__ */` | `window.PRESET_IMAGES = {...}` |
| `/* __APP_JS__ */`  | Minified JavaScript from `app.tsx` |

The output file is self-contained except for the React CDN scripts.

**Important:** Preset PNGs live on disk under `device_libs` but are often gitignored locally. You must have those files present when running `npm run build`, or the build fails with “No preset PNGs found”.

---

## Runtime stack (`template.html` + `app.tsx`)

### UI shell

`template.html` provides:

- Dark-theme CSS (layout, stepper, sliders, drop zone, canvas containers).
- React 18 and ReactDOM from unpkg CDN.
- `<div id="root">` mount point.

### State model

The main `App` component holds workflow state:

| State | Role |
| ----- | ---- |
| `device` | Selected controller id (`ws2p8`, etc.) |
| `step` | Current workflow step (see below) |
| `deviceLocked` | Device dropdown disabled after upload starts |
| `sourceCanvas` | User's uploaded photo |
| `wheelCrops` | Two ellipse-cropped wheel images |
| `newCanvas` | Polygon-cropped car body (wheels excluded) |
| `carExportCanvas` | Final car image at preset resolution (after align step) |
| `overlayX/Y/Scale` | Car alignment on reference |
| `w1x/w1y`, `w2x/w2y` | Wheel alignment (scale locked to 1.0) |

Preset reference canvases (`origCanvas` for car, `wheelsCanvas` for wheels) reload when the device changes.

---

## User workflow

The stepper mirrors the Python tool's sequence:

```
Upload → Wheel 1 → Wheel 2 → Car outline → Align car → Align wheels → Download .c files
```

### 1. Device selection + upload

User picks a controller variant. That choice sets:

- Reference car size (`carW` × `carH`)
- Reference wheels size (`wheelsW` × `wheelsH`)
- Background images used in alignment previews

User uploads PNG or JPG via file picker or drag-and-drop. The device is locked for the rest of the session so export dimensions stay consistent.

### 2. Wheel outlining (×2)

Each wheel uses a **three-point ellipse**:

1. Click center of the wheel.
2. Click a point on the rim (defines first axis).
3. Click another rim point (defines second axis).

The ellipse is approximated as a 64-point polygon (`ellipsePolygonPoints()`), then cropped with `extractEllipseCrop()`. Handles can be dragged to refine the shape.

Wheel 1 crop is stored, then the user repeats for wheel 2 on the same source photo.

### 3. Car body outlining

User clicks polygon vertices around the car **excluding** the wheels. `extractPolygonCrop()`:

1. Computes bounding box of all points.
2. Creates a transparent canvas of that size.
3. Builds a clip path from the polygon.
4. Draws the source image offset so only the interior remains.

### 4. Align car + export `img_car_custom.c`

The cropped car is composited over the device's `img_car.png` reference:

- **Preview:** reference at full opacity + new car at 88% opacity (`OVERLAY_ALPHA = 0.88`).
- **Sliders:** X, Y, and scale (0.05–1.5, same range as the Python tool).

Export uses `buildExportImage()`: a canvas exactly `carW` × `carH` with **only** the aligned car (transparent background). No reference layer is baked in.

Clicking download runs `downloadLvglC(exportCanvas, "img_car_custom", "img_car_custom.c")`.

The export canvas is also saved in `carExportCanvas` for the wheels step.

### 5. Align wheels + export `img_wheels_custom.c`

The cropped wheels are composited over the device's `img_wheels.png` reference. The previously exported car image is drawn faintly (`CAR_ON_WHEELS_ALPHA = 0.25`) as a positioning guide.

Each wheel has independent X/Y sliders; scale is fixed at 1.0 (matching the Python tool's wheels step).

Export uses `buildWheelsExportImage()` at `wheelsW` × `wheelsH`.

---

## Image processing (Canvas 2D)

The Python tool uses Pillow (`Image`, `ImageDraw`, alpha compositing). The web port uses the same math with HTML5 Canvas:

| Python (Pillow) | Web (Canvas) |
| --- | --- |
| `Image.open()` | `loadImageCanvas()` / `loadFileCanvas()` |
| Polygon mask + crop | `ctx.clip()` + `drawImage()` |
| `Image.alpha_composite` | `ctx.globalAlpha` + layered `drawImage()` |
| Resize for preview | Scale factor from `previewMax / origW` |
| Export at native size | Dedicated export canvases at preset dimensions |

All intermediate results are `HTMLCanvasElement` instances in memory. Nothing is uploaded to a server.

### Key constants (shared with Python)

```typescript
OVERLAY_SCALE_MIN = 0.05
OVERLAY_SCALE_MAX = 1.5
OVERLAY_ALPHA = 0.88
CAR_ON_WHEELS_ALPHA = 0.25
```

---

## LVGL C export (RGB565A8)

Previously, users downloaded PNGs and converted them externally. The web app now generates `.c` files in the same format as LVGL v9's online converter and the project's device_lib presets.

### Color format: `LV_COLOR_FORMAT_RGB565A8`

Each pixel occupies **3 bytes** in the array, but memory layout is **two planes**, not interleaved RGBA:

```
[ RGB565 byte 0 ][ RGB565 byte 1 ]  × (width × height)   ← color plane
[ alpha byte ]                      × (width × height)   ← alpha plane
```

Total array size = `width × height × 3`.

### Conversion: `canvasToRgb565A8()`

1. Read RGBA pixels with `getImageData()`.
2. For each pixel, quantize to RGB565:
   - R: 5 bits (`r >> 3`)
   - G: 6 bits (`g >> 2`)
   - B: 5 bits (`b >> 3`)
   - Packed: `(r5 << 11) | (g6 << 5) | b5`
3. Store as **little-endian** uint16 (low byte first, then high byte).
4. Append full 8-bit alpha values in row-major order after the color plane.

### C file generation: `generateLvglCFile()`

Output structure matches `Wireless_Controller/device_libs/ws2p8/images/presets/img_car.c`:

```c
#include "lvgl.h"   // or "lvgl/lvgl.h" depending on include style

const LV_ATTRIBUTE_MEM_ALIGN LV_ATTRIBUTE_LARGE_CONST
      LV_ATTRIBUTE_IMAGE_IMG_CAR_CUSTOM uint8_t img_car_custom_map[] = {
  0x00, 0x00, ...   // 16 bytes per line
};

const lv_image_dsc_t img_car_custom = {
  .header.cf = LV_COLOR_FORMAT_RGB565A8,
  .header.magic = LV_IMAGE_HEADER_MAGIC,
  .header.w = <width>,
  .header.h = <height>,
  .data_size = <width * height> * 3,
  .data = img_car_custom_map,
};
```

`formatCArrayBytes()` writes hex literals (`0xHH`) with 16 bytes per line for readability.

### Download

`downloadLvglC()` builds the string in memory and triggers a browser download via `Blob` + temporary `<a download>` — no server round trip.

---

## Firmware integration
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

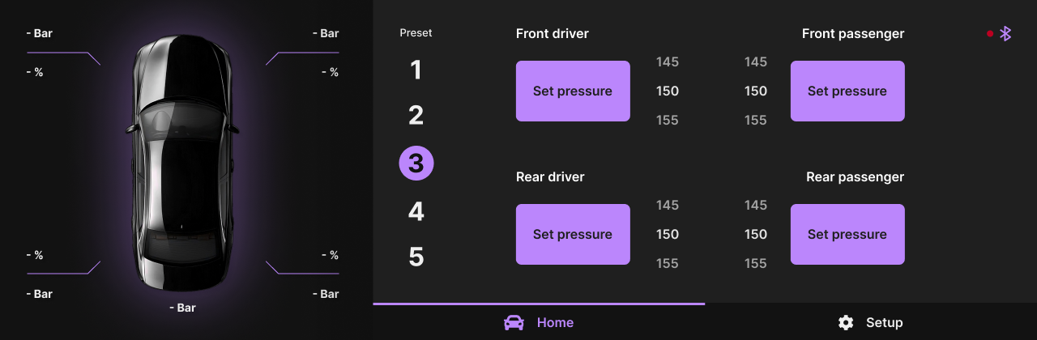
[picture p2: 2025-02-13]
MobileApp/oasman_mobile/assets/Frame 61.png

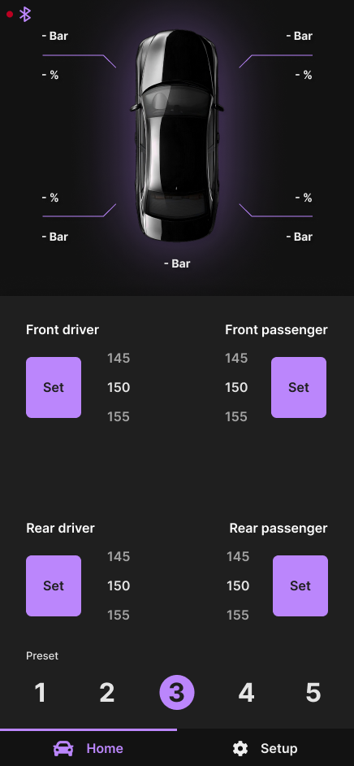
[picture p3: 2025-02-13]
MobileApp/oasman_mobile/assets/Home-1.png

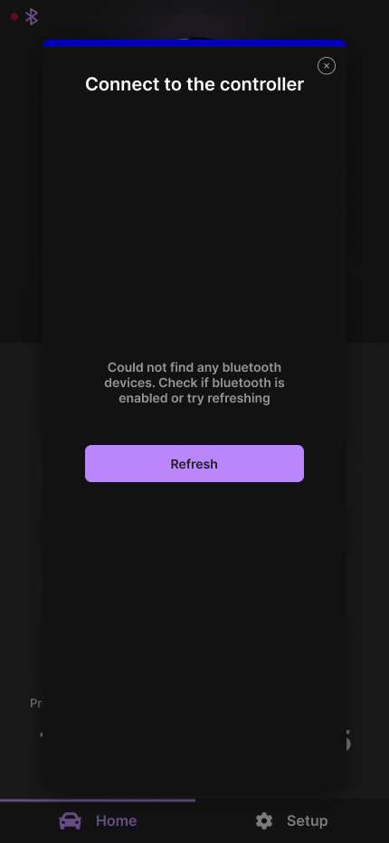
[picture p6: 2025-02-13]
MobileApp/oasman_mobile/assets/No bluetooth devices.png

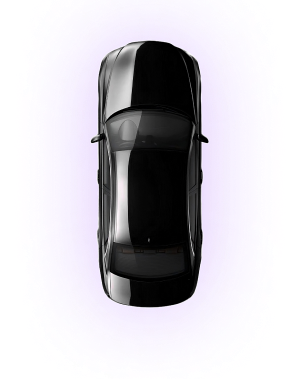
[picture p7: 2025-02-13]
MobileApp/oasman_mobile/assets/car_black-transformed1.png

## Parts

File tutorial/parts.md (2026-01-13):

# Parts list

Here are the parts required to build the system.

### PCB Parts (For the SMD pcb)

| Part Name  | qty | image | Link | info |
| --- | --- | --- | --- | --- |
| Main PCB | 1 |  | [files](https://github.com/gopro2027/ArduinoAirSuspensionController/tree/main/PCB/ESP32_30PIN_PCB/) | The new pre assembled SMD pcb cost a decent amount to order straight from JLCPCB so join the discord and find a reseller to pick one up cheaper than ordering the minimum qty from jlcpcb directly if possible. Please read the readme files! As of 9/3/2025 the latest version is 4.0 |
| ESP32 30pin | 1 |  | [amazon](https://www.amazon.com/Teyleten-Robot-ESP-WROOM-32-Development-Microcontroller/dp/B08246MCL5/) | The project currently uses an esp32 wroom 30pin. Avoid the boards with the rectangular CH340 chip. Purchase boards with the square CP2102 chips. CH340 is a cheap chip and is indicitive of a bad quality board and may cause bluetooth issues. |
| HCTL HC-MX3.0-2&ast;6Y | 2 |  | [lcsc](https://www.lcsc.com/product-detail/C3294363.html) | 2x6 molex microfit connector. For manifold connector and pressure sensors |
| HCTL HC-MX3.0-2&ast;3Y | 1 |  | [lcsc](https://www.lcsc.com/product-detail/C3294360.html) | 2x3 molex microfit connector. For IO port |
| HCTL HC-MX3.0-2&ast;4Y | 2 |  | [lcsc](https://www.lcsc.com/product-detail/C3294361.html) | -*Optional*- 2x4 molex microfit connector. For level sensors, 128x64 oled display, and gps |
| CJT(Changjiang Connectors) C3030F-TP-A (MOLEX MICROFIT PINS) | 48 (30 without optional microfits) |  | [lcsc](https://www.lcsc.com/product-image/C882167.html) | You need a minimum of 30 of these for the required connectors, or 48 for every connector. Please ensure you buy a few more than you will need in case you mess up some. |
| 5a mini fuse | 1 |  | - | 5 amp fuse for the board. Previously 3amp but some solenoids solenoids (manifold) will pull more than that. |
| 128x64 I2C OLED | 1 |  | [amazon](https://www.amazon.com/gp/product/B09JWLDK9F/) [aliexpress](https://www.aliexpress.com/item/1005005241315177.html) | -*Optional*- Depending on which one you purchase, you may need to change the i2c address in the esp32 configuration file. Some have solderable address configuration on the back of the screen/board |

<!--| JST-XH 2.54mm  |    Assorted (2-6)     | ![image](https://github.com/user-attachments/assets/f83d2230-f445-4e51-9718-cc29dfb26ecd) | [amazon](https://www.amazon.com/Connector-Housing-Adapter-Terminal-Connectors/dp/B0BZDCGJ32/) | You will need multiple of each size, so it's best to purchase an assorted pack that includes 2,3,4, and 6.<br> 4pin x 1 for main i/o<br>4pin x 1 for screen<br>3pin x 11 for valvetable, pressure sensors, height sensors, power<br> 6pin x 1 for other half of valvetable | -->
<!--| 5x20 3a fuse |   1      | ![image](https://github.com/user-attachments/assets/eb0c0166-c211-451b-9961-f7c7b3954020) | [lcsc fuse](https://www.lcsc.com/product-detail/Disposable-fuses_Reomax-STC1300_C5381727.html) | Fuse for the board |-->

### Controller Parts
| Part Name  | qty | image | Link | info |
| --- | --- | --- | --- | --- |
| Waveshare 2.8" ESP32-S3 | 1 |  | [amazon](https://www.amazon.com/Capacitive-Development-Peripheral-Interfaces-Resolution/dp/B0D8KKRV5V/) | This is our default controller for OASMan. It is built with quality and runs smoothly. If you have fat fingers you may find it a bit small, join the discord and ask larger devices we support. |
| Battery | 1 |  | [amazon](https://www.amazon.com/dp/B0DPZVBKMY) | -*Optional*- You need a small battery (600ma or more) with a jst 1.25 connector if you want the controller to work without being plugged in (aka wirelessly). Works on either controller. |
| M2.5x12mm Countersunk Socket Cap Screws | 4 |  | [amazon exact length](https://www.amazon.com/PATIKIL-M2-5x12-Countersunk-Machine-Spanner/dp/B0FSL8TN4C?th=1) <br><br> [amazon variety length pack](https://www.amazon.com/dp/B07Y6ZZ674) | -*Optional*- Specifically for the waveshare 2.8" device. If you measure them with a caliper they will come out closer to 11.75mm in length. Screws may vary depending on which one you use. |
| 3D printed case | 1 | - | - | -*Optional*- You are going to want to 3d print the files for assembling the case. If you don't own a 3d printer, you will want to order these files printed online or from one of the discord members |

### Manifold Parts

| Part Name  | qty | image | Link | info |
| --- | --- | --- | --- | --- |
| (Option #1) Generic Ebay Manifold & Pressure sensors kit | 1 |  | [amazon](https://www.amazon.com/Display-Suspension-Manifold-Controller-Solenoid/dp/B0F1STPNBH)<!--[ebay](https://www.ebay.com/itm/324238773355)--> | This is a nice kit of manifold + pressure sensors for $150. Of you can purchase them separate like option #2 below. The guage is not used btw! <br><br>-*NOTE*- There are some reports of bad solder quality on the connector. You may want to reflow the connector or purchase a different manifold to ensure safety. |
| (Option #2.a) Generic Ebay Manifold | 1 |  | [ebay](https://www.ebay.com/itm/175635451020)<!--[ebay](https://www.ebay.com/itm/324238773355) price went up $20 on this one --> | All the documentation is based on this manifold and it's wiring. If you use a different manifold you need to follow the wiring diagrams on the PCB carefully <br><br>-*NOTE*- There are some reports of bad solder quality on the connector. You may want to reflow the connector or purchase a different manifold to ensure safety. |
| (Option #2.b) 200PSI pressure sensor | 5 |  | [amazon](https://www.amazon.com/dp/B0BYHW1R2Z) | This is a kit, we will not be using the screen, but it is cheaper than buying individually and more reliable than purchasing the sensors from a random supplier, as they often end up being duds. This kit also includes plenty of wiring, eliminating the need to purchase more wiring for the pressure sensors |
| 18 Gauge 6 Conductor Electrical Wire | 10ft+ |  | [amazon](https://www.amazon.com/DEKIEVALE-Conductor-Electrical-Stranded-Extension/dp/B0BX8T5ZFN/?th=1) | You need 4 wires to handle 12v, ground, acc, and compressor, and then 2 more optionally for e-brake and auxillary output |
| Various 1/8 NPT PTC connectors | 0-12 | - | - | Depending on your setup you may configure the ports differently. Easiest route is using all PTC and 1/4" hoses to everything. For a typical manifold with 4 faces, and 2 on each end, you would use 5 1/4npt DOT approved push to connec connectors, then 1 1/4npt muffler for the output (or another 1/4npt PTC connector), then 2 1/4npt plugs for the other end of the manifold. |
| 3D printed manifold base hat and lid | 1 | - | - | You are going to want to 3d print the files for assembling the manifold and pcb together in a nice package. If you don't own a 3d printer, you will want to order these files printed online or from one of the discord members |
<!-- | 12V Stabilizer | 1 | ![20241205_131439](https://github.com/user-attachments/assets/77595e2d-b98f-428d-9c74-689fca6c2d4f) | [amazon](https://www.amazon.com/YABOANG-9-40V-12V3A-Transformer-Instruments/dp/B0CZ8GYJC5?th=1) | Car electronics are not a perfect 12v, would be a good idea to run one of these on the 12v input to stabilize the voltage and help prevent possible issues | -->

### Additional Parts

| Part Name  | qty | image | Link | info |
| --- | --- | --- | --- | --- |
| Relay | 2 |  | [amazon](https://www.amazon.com/gp/product/B07T35K8S2) | You also may want a relay to control the compressor and the optional auxillary output. (Please double check your requirements for the compressor relay and amps!!!!! Requirements vary depending on your compressor setup, which is out of the scope of OAS-Man. OAS-Man only supplies the signal of when to turn on the compressor, not the full power.) |

<!--
### (Outdated) PCB Board v2.0 required parts
| Part Name  | qty | image | Link | info |
| --- | --- | --- | --- | --- |
| FQP30N06L mosfet | 11 | ![image](https://github.com/user-attachments/assets/a3c97586-92e9-4a2b-ac86-40f317dc5ced) | [ebay](https://www.ebay.com/itm/171395648380) | Linked is a pack of 50 | 
| CN3903 5V buck converter | 1 | ![image](https://github.com/user-attachments/assets/3115a607-604a-47f0-9996-0a4113feee0c) | [amazon](https://www.amazon.com/dp/B0C69DP5RK)  [aliexpress](https://www.aliexpress.us/item/3256802647847616.html) | No pin headers required, surface mount | 
| 2.54mm pin headers | Assorted | ![image](https://github.com/user-attachments/assets/4e66a6ba-f1f2-48e0-b0ac-b6fcbb015b4c) | [amazon](https://www.amazon.com/gp/product/B0BX865TRT/ref=ewc_pr_img_3?smid=A1F2OO11SCJ7V3&th=1) [aliexpress](https://pl.aliexpress.com/item/1005006468451122.html) | You need 2 x 15 female headers for mounting the esp32 so there is space under it. Also recommended to mount the ads1115's on these too. | 
| ADS1115 | 2 | ![image](https://github.com/user-attachments/assets/31fdfe86-8bbc-4eab-8224-19a8565d94ff) | [amazon](https://www.amazon.com/gp/product/B0CNV9G4K1) [aliexpress](https://pl.aliexpress.com/item/1005006074781549.html) | You can opt to purchase and install only 1 if you disable the height sensor code in the esp32 configuration file. | 
| 4 Channels IIC I2C Logic Level Converter Bi-Directional 3.3V-5V Shifter Module | 1 | ![image](https://github.com/user-attachments/assets/3a9aa1b9-83d0-4efb-8649-06e1c845b9c5) | [amazon](https://www.amazon.com/dp/B07F7W91LC) [aliexpress](https://pl.aliexpress.com/item/1005005984772131.html) | Pin headers required (as pictured) | 
| PTF-77 Fuse Holder and 5x20 3a fuse | 1 | ![image](https://github.com/user-attachments/assets/6d67dbb4-81c1-4b15-9bf6-52c54b36e47f) | [lcsc holder](https://www.lcsc.com/product-detail/Fuseholders_XFCN-PTF-77_C717030.html)<br> [lcsc fuse](https://www.lcsc.com/product-detail/Disposable-fuses_Reomax-STC1300_C5381727.html) | Purchase from lcsc with the resistors and maybe the diodes too. You can skip the fuse holder and solder in the fuse directly if you prefer. Or skip entirely, solder in a wire, and wire a fuse externally. | 
| 1/4w 12x 10K, 11x 150R, 1x 1K, 1x 2K | Assorted | ![image](https://github.com/user-attachments/assets/7492bb33-a26f-439b-a489-2b17d04ce9f2) | [lcsc 10k](https://www.lcsc.com/product-detail/Through-Hole-Resistors_VO-MF1-4W-10K-1-ST52_C2903232.html)<br> [lcsc 150R](https://www.lcsc.com/product-detail/Through-Hole-Resistors_VO-MF1-4W-150-1-ST52_C2903242.html)<br> [lcsc 1K](https://www.lcsc.com/product-detail/Through-Hole-Resistors_VO-MF1-4W-1K-1-ST52_C2903245.html)<br> [lcsc 2K](https://www.lcsc.com/product-detail/Through-Hole-Resistors_VO-MF1-4W-2K-1-ST52_C2903278.html) | 1/4w, 1% resistors (blue), purchase 100 of each from lcsc for cheap | 
| 1N4007 diode | 13 | ![image](https://github.com/user-attachments/assets/daae6c1d-b7ca-4330-b604-794b2f88379b) | [ebay](https://www.ebay.com/itm/235235061574) [aliexpress](https://pl.aliexpress.com/item/1005006003747959.html) [lcsc](https://www.lcsc.com/product-detail/Diodes-General-Purpose_Yangzhou-Yangjie-Elec-Tech-1N4007_C2986225.html) | Linked is a pack of 100 | 
-->

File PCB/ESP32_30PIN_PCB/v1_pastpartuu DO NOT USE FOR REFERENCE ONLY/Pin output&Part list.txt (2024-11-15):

websites: digikey, amazon, ebay, aliexpress

Pin Outputs & Partlist.

Power in/Compressor relay out.
1.+12v In.
2.Gnd.
3.Output to Compressor relay.
4.Gnd.

MINI-FIT JR, 2X2, 90 DEG, 39300040
https://www.digikey.com/en/products/detail/molex/0039300040/930321
````````````````````````````````````````````

Valvetable Pinout.
1.+12v Out
2.Rear Right Up (D23)
3.Rear Right Down (D19)
4.Rear Left Up (D18)
5.Rear Left Down (D17)
6.Front Left Down (D27)
7.Front Left Up (D26)
8.Front Right Down (D25)
9.Front Right Up (D33)
10.Empty

CON-MOLEX-MICRO-FIT-3_0_43045-1000
https://www.digikey.com/en/products/detail/molex/0430451000/252530
or
https://www.amazon.com/0430451000-Connector-Header-Through-Position/dp/B0CLCFTHJG/

````````````````````````````````````````````

Pressure Sensors. FL, FR, RL, RR and Tank.
1.+5v Output to sensor
2.Signal
3.Gnd.

XH2.54-3P 3 Pin Curved.
https://www.amazon.com/XH2-54-3P-Curved-Spacing-Connectors-Terminals/dp/B0CRKN1LPX
or cheaper:
https://www.amazon.com/Connector-Housing-Adapter-Terminal-Connectors/dp/B0BZDCGJ32/ (assortment, 3 and 4 pin) (added by gopro_2027)
````````````````````````````````````````````

Oled Screen output.
1.3.3v
2.Gnd.
3.SCL
4.SDA

XH2.54 2.54mm 4P Straight Male.
https://www.amazon.com/Straight-Housing-Terminal-Connector-Assortment/dp/B0CSTBM8GP
or cheaper:
https://www.amazon.com/Connector-Housing-Adapter-Terminal-Connectors/dp/B0BZDCGJ32/ (assortment, 3 and 4 pin) (added by gopro_2027)
````````````````````````````````````````````

Mosfets.
9X FQP30N06L
https://www.ebay.com/itm/171395648380 (added by gopro_2027)
````````````````````````````````````````````

5V Step Down Converter.
CN3903 5V 3A Mini DC-DC Buck Step Down Converter.
https://www.aliexpress.us/item/3256802647847616.html?gatewayAdapt=glo2usa4itemAdapt
or
https://www.amazon.com/DAOKAI-Module-Converter-Voltage-Regulator/dp/B0C69DP5RK (added by gopro_2027)
````````````````````````````````````````````

ESP32-WROOM 30Pin
https://www.aliexpress.com/item/1005006336964908.html?spm=a2g0o.order_list.order_list_main.15.7c3f1802cRxb86
or
https://www.amazon.com/Teyleten-Robot-ESP-WROOM-32-Development-Microcontroller/dp/B08246MCL5/ (added by gopro_2027)
````````````````````````````````````````````

Oled.
2.4" 2.42 inch 128x64 OLED LCD Display Module or 0.96 Inch OLED SSD1306 .
https://www.aliexpress.com/item/1005005241315177.html?spm=a2g0o.order_list.order_list_main.147.7c3f1802cRxb86
or
https://www.amazon.com/gp/product/B09JWLDK9F/ (added by gopro_2027)
````````````````````````````````````````````

Diodes.
10X 1N4007
https://www.ebay.com/itm/235235061574 (added by gopro_2027)
````````````````````````````````````````````

Resistors.
9X 150R
9X 10K
5X 1K
5X 2K
Just order an assorted set :)
````````````````````````````````````````````

ESP32-WROOM 30Pin.
Pressure read (Analog input signal)
GPIO36 ADC Tank Pressure
GPIO39 ADC Front Right
GPIO34 ADC Front Left
GPIO35 ADC Rear Right
GPIO32 ADC Rear Left

Output Mosfets.(Valvetable)
GPIO33 Front Right Up
GPIO25 Front Right Down
GPIO26 Front Left Up
GPIO27 Front Left Down

(Compressor Control)
GPIO13 Compressor

GPIO23 Rear Right Up
GPIO22 i2c scl (Screen)
GPIO21 i2c sda (Screen)
GPIO19 Rear Right Down
GPIO18 Rear Left Up
GPIO17 Rear Left Down
````````````````````````````````````````````

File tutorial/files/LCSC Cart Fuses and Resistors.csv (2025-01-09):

LCSC Part Number | Manufacture Part Number | Manufacturer | Package | Customer # | Description | RoHS | Order Qty. | Min\Mult Order Qty. | Unit Price($) | Ext.Price($) | Product Link
C717030 | PTF-77 | XFCN | - |  | Fuseholders ROHS | yes | 5 | 5 | 0.1301 | 0.65 | https://www.lcsc.com/product-detail/fuseholders_xfcn-ptf-77_C717030.html
C2903232 | MF1/4W-10K±1%-ST52 | VO | Plugin,D2.7xL6.2mm |  | Metal Film Resistors 10kΩ 250mW ±100ppm/℃ ±1% Plugin,D2.7xL6.2mm Through Hole Resistors ROHS | yes | 100 | 100 | 0.0044 | 0.44 | https://www.lcsc.com/product-detail/through-hole-resistors_vo-mf1-4w-10k-1-st52_C2903232.html
C2903242 | MF1/4W-150Ω±1%-ST52 | VO | Plugin,D2.7xL6.2mm |  | Metal Film Resistors 150Ω 250mW ±100ppm/℃ ±1% Plugin,D2.7xL6.2mm Through Hole Resistors ROHS | yes | 100 | 100 | 0.0042 | 0.42 | https://www.lcsc.com/product-detail/through-hole-resistors_vo-mf1-4w-150-1-st52_C2903242.html
C2903278 | MF1/4W-2K±1%-ST52 | VO | Plugin,D2.7xL6.2mm |  | Metal Film Resistors 2kΩ 250mW ±100ppm/℃ ±1% Plugin,D2.7xL6.2mm Through Hole Resistors ROHS | yes | 100 | 100 | 0.0046 | 0.46 | https://www.lcsc.com/product-detail/through-hole-resistors_vo-mf1-4w-2k-1-st52_C2903278.html
C2903245 | MF1/4W-1K±1%-ST52 | VO | Plugin,D2.7xL6.2mm |  | Metal Film Resistors 1kΩ 250mW ±100ppm/℃ ±1% Plugin,D2.7xL6.2mm Through Hole Resistors ROHS | yes | 100 | 100 | 0.0046 | 0.46 | https://www.lcsc.com/product-detail/through-hole-resistors_vo-mf1-4w-1k-1-st52_C2903245.html
C5381727 | STC1300 | Reomax | Plugin,D5xL20mm |  | Glass Tube Fuse 3A Plugin,D5xL20mm Disposable fuses ROHS | yes | 10 | 10 | 0.0572 | 0.57 | https://www.lcsc.com/product-detail/disposable-fuses_reomax-stc1300_C5381727.html

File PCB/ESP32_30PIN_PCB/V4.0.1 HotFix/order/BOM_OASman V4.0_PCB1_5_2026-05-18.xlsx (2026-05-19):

No. | Quantity | Comment | Designator | Footprint | Value | Manufacturer Part | Manufacturer | Supplier Part | Supplier
1 | 4 | 1uF | C1,C2,C5,C6 | C0603 | 1uF | GRM188R61H105KAALD | muRata(村田) | C77386 | LCSC
2 | 1 | 100nF | C12 | C0402 | 100nF | CL05B104KB54PNC | SAMSUNG(三星) | C307331 | LCSC
3 | 2 | 22uF | C13,C14 | C0805 | 22uF | CL21A226MAQNNNE | SAMSUNG(三星) | C45783 | LCSC
4 | 2 | 10uF | C15,C16 | C1206 | 10uF | CL31A106KBHNNNE | SAMSUNG(三星) | C13585 | LCSC
5 | 1 | 1000uF | C17 | CAP-SMD_BD10.0-L10.3-W10.3-FD | 1000uF | EEEFT1E102UP | PANASONIC(松下) | C401766 | LCSC
6 | 2 | HC-MX3.0-2*6A | CN2,CN3 | CONN-TH_12P-P3.00_HC-MX3.0-2X6A |  | HC-MX3.0-2*6A | HCTL(华灿天禄) | C3294375 | LCSC
7 | 2 | HC-MX3.0-2*4A | CN4,CN5 | CONN-TH_8P-P3.00_HC-MX3.0-2X4A |  | HC-MX3.0-2*4A | HCTL(华灿天禄) | C3294373 | LCSC
8 | 1 | HC-MX3.0-2*3A | CN7 | CONN-TH_6P-P3.00_HC-MX3.0-2X3A |  | HC-MX3.0-2*3A | HCTL(华灿天禄) | C3294372 | LCSC
9 | 13 | SM4007PL | D1,D2,D3,D4,D5,D6,D7,D8,D9,D10,D15,D16,D17 | SOD-123F_L2.8-W1.8-LS3.7-RD |  | SM4007PL | MDD(辰达半导体) | C64898 | LCSC
10 | 1 | XF-508P-B-B | F2 | FUSE-TH_4P-L16.0-W6.7 |  | XF-508P-B-B | XFCN(兴飞) | C19727305 | LCSC
11 | 1 | 3.3uH | L3 | IND-SMD_L4.5-W4.1_SL0420 | 3.3uH | SL0420-3R3M | 台湾陆海 | C22463807 | LCSC
12 | 11 | MDT30N06L | Q1,Q2,Q3,Q4,Q5,Q6,Q7,Q8,Q9,Q14,Q16 | TO-252-2_L6.6-W5.6-P4.60-LS9.7-BR |  | MDT30N06L | minos(迈诺斯) | C5240683 | LCSC
13 | 2 | BSS138 | Q12,Q13 | SOT-23-3_L2.9-W1.6-P1.90-LS2.8-BR |  | BSS138 | SHIKUES(时科) | C112239 | LCSC
14 | 1 | MDT35P10D | Q15 | TO-252-2_L6.6-W6.1-P4.57-LS9.9-BR-CW |  | MDT35P10D | minos(迈诺斯) | C5890267 | LCSC
15 | 19 | 10kΩ | R1,R2,R3,R4,R5,R6,R7,R8,R18,R23,R25,R27,R28,R29,R30,R37,R39,R53,R54 | R1206 | 10kΩ | 1206W4F1002T5E | UNI-ROYAL(厚声) | C17902 | LCSC
16 | 11 | 150Ω | R9,R10,R11,R12,R13,R14,R15,R16,R17,R38,R55 | R1206 | 150Ω | FRC1206J151 TS | FOJAN(富捷) | C2907432 | LCSC
17 | 1 | 1kΩ | R19 | R1206 | 1kΩ | FRC1206J102 TS | FOJAN(富捷) | C2907440 | LCSC
18 | 1 | 2kΩ | R24 | R1206 | 2kΩ | FRC1206J202 TS | FOJAN(富捷) | C2907466 | LCSC
19 | 6 | 1MΩ | R33,R41,R42,R43,R44,R45 | R1206 | 1MΩ | 1206W4F1004T5E | UNI-ROYAL(厚声) | C17927 | LCSC
20 | 1 | 3kΩ | R40 | R1206 | 3kΩ | 1206W4F3001T5E | UNI-ROYAL(厚声) | C18012 | LCSC
21 | 1 | 56.2kΩ | R50 | R0402 | 56.2kΩ | 0402WGF5622TCE | UNI-ROYAL(厚声) | C54968 | LCSC
22 | 1 | 10kΩ | R51 | R0402 | 10kΩ | 0402WGF1002TCE | UNI-ROYAL(厚声) | C25744 | LCSC
23 | 2 | ADS1115IDGSR | U4,U5 | MSOP-10_L3.0-W3.0-P0.50-LS5.0-BL |  | ADS1115IDGSR | TI(德州仪器) | C37593 | LCSC
24 | 2 | PM2.54-1*15 | U7,U8 | HDR-TH_15P-P2.54-V-F |  | PM2.54-1*15 | ZHOURI(洲日) | C5371989 | LCSC
25 | 4 | GZ2012D152TF | U9,U10,U11,U12 | L0805 |  | GZ2012D152TF | Sunlord(顺络) | C96710 | LCSC
26 | 1 | TPS563200DDCR | U13 | SOT-23-6_L2.9-W1.6-P0.95-LS2.8-BR |  | TPS563200DDCR | TI(德州仪器) | C97253 | LCSC
27 | 1 | MMSZ4684 | ZD1 | SOD-123_L2.8-W1.8-LS3.7-RD |  | MMSZ4684 | CJ(江苏长电/长晶) | C21510 | LCSC

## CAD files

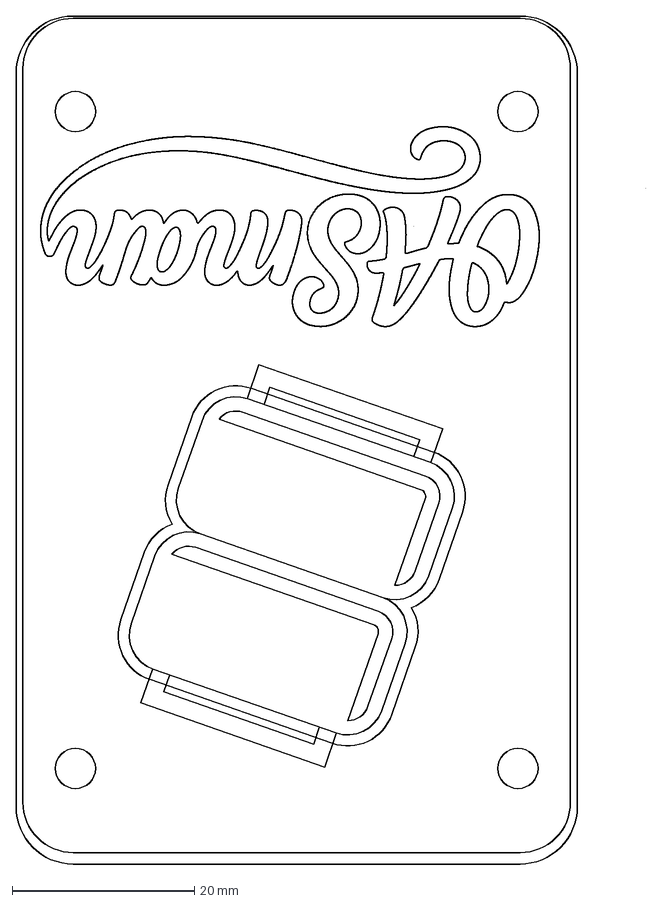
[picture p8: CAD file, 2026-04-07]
3d Prints/other/Waveshare 3.5 Faux Remix/OASman Logo Faux Remix.dxf
69.0 x 92.9 mm

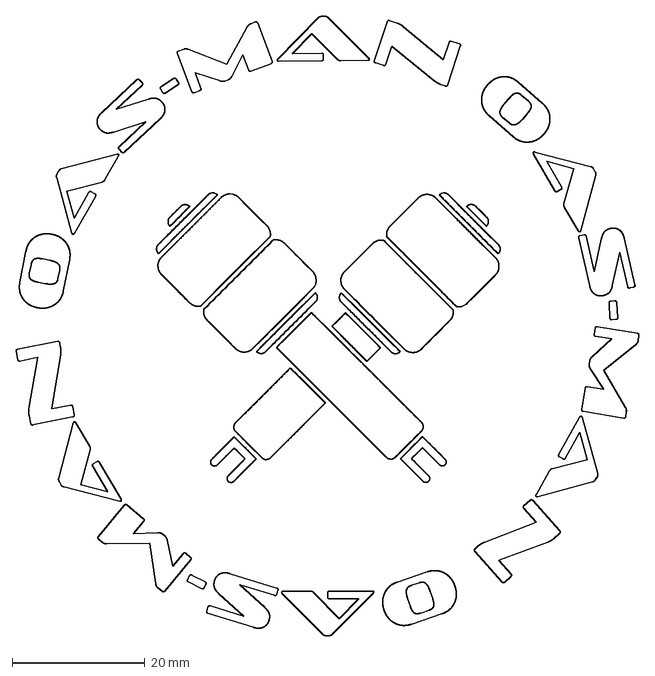
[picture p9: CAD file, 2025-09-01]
3d Prints/other/cup coaster/oasman icon.dxf
94.0 x 93.4 mm

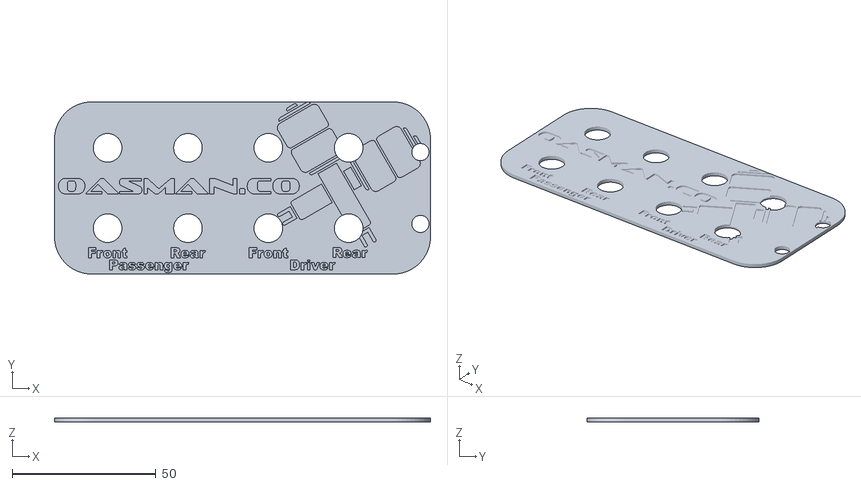
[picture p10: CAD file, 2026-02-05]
3d Prints/manifold decorative plate.stl
131.0 x 60.0 x 1.50

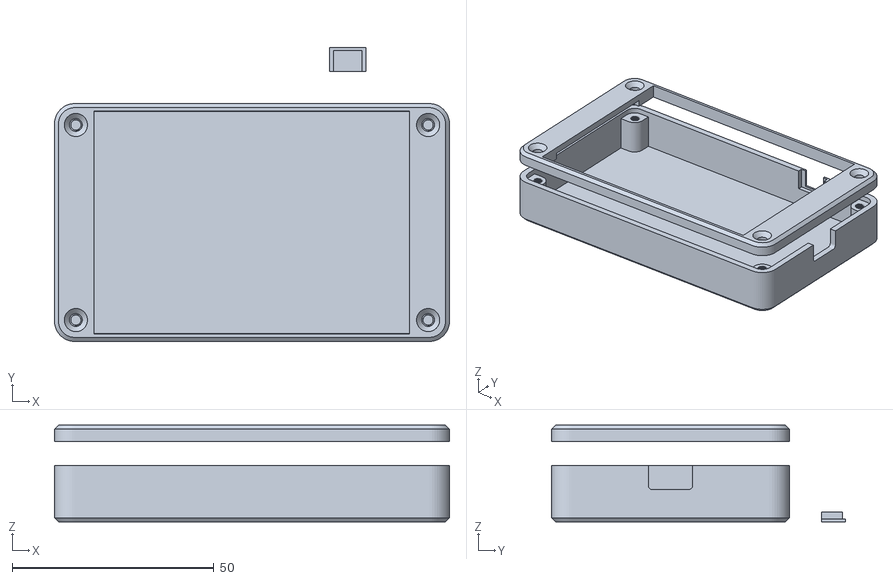
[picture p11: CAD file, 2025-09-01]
3d Prints/other/3.2 inch screen case/3.2 inch CYD screen container v19 - gopro_2027's design.stl
98.0 x 72.9 x 24.0

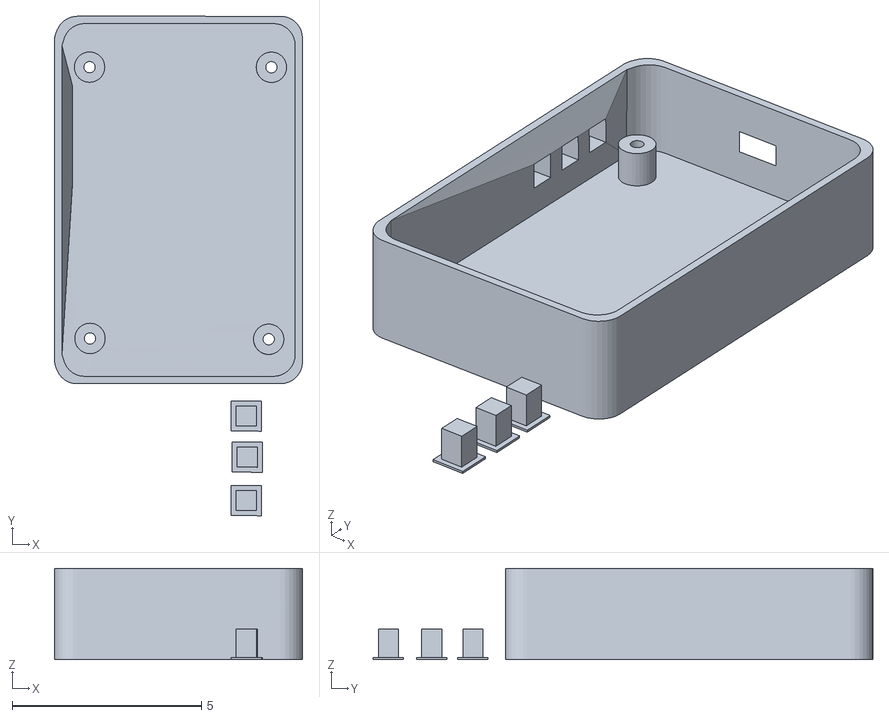
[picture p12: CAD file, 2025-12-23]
3d Prints/other/3.5 screen Hersh/3.5remoteHersh.stl
6.55 x 13.2 x 2.41

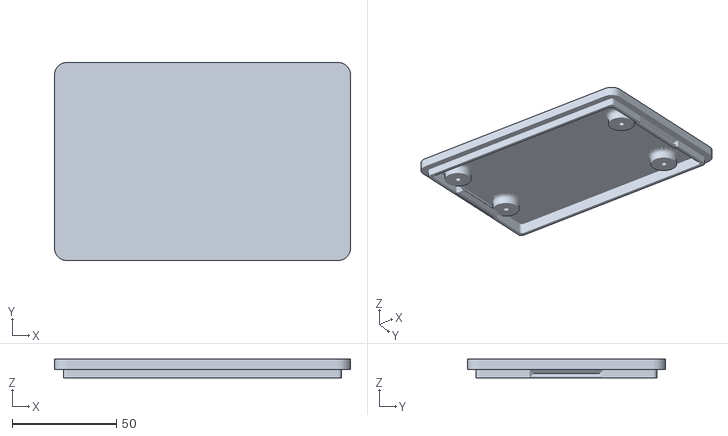
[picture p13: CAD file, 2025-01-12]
3d Prints/other/Box for pcb only/Snapfit PCB Base.stl
142.0 x 95.0 x 9.00

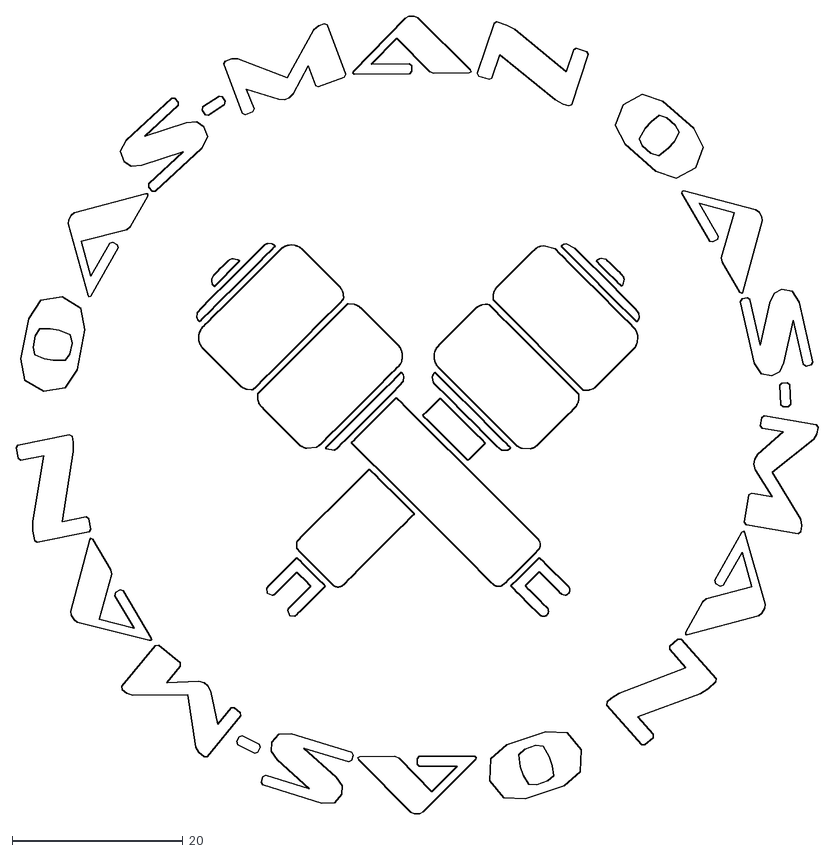
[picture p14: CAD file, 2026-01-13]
3d Prints/other/cup coaster/coaster_v6_1775440253.dxf
94.0 x 93.4

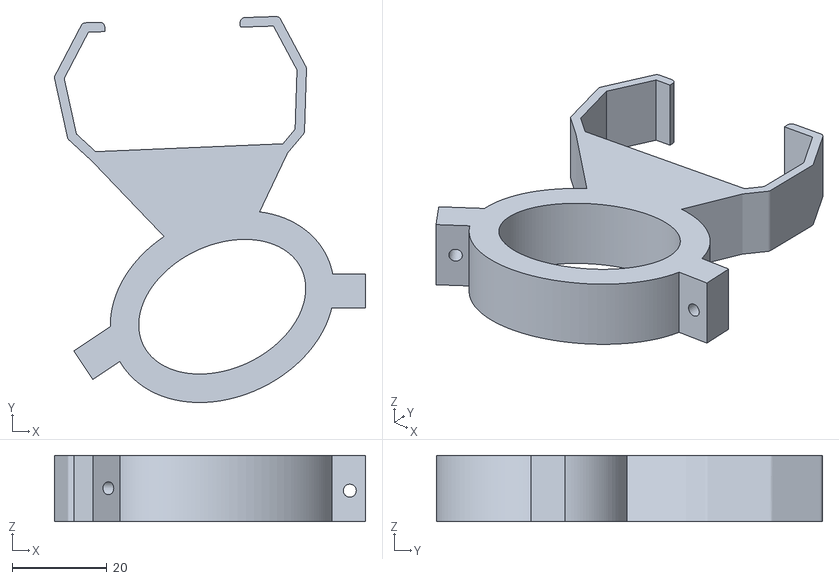
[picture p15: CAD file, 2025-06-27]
3d Prints/other/ps3 holder/ps3 holder v2.stl
65.6 x 81.4 x 14.0

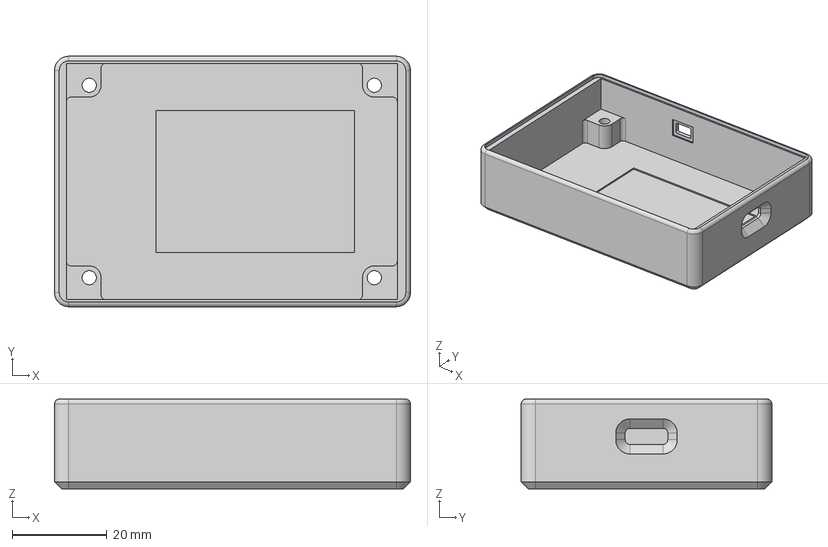
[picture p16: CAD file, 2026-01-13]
3d Prints/other/screen container 1-12-2026.step
75.3 x 53.0 x 19.0 mm

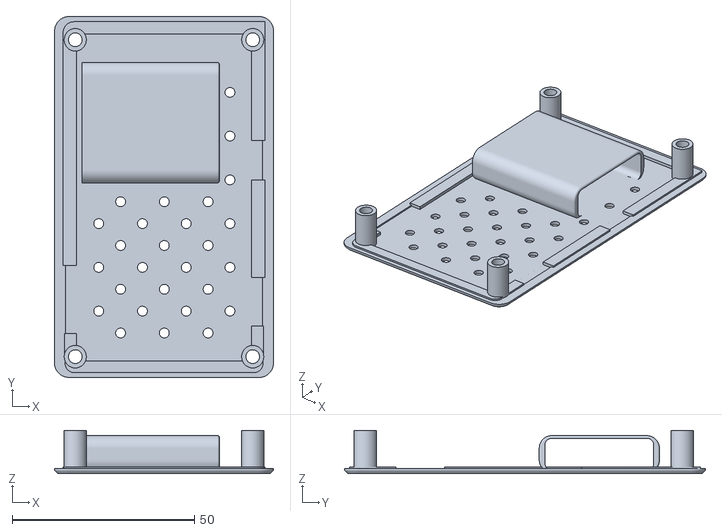
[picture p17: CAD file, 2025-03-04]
3d Prints/other/3.2 inch screen case/touch remote fixed bottom battery sleeve.stl
60.1 x 99.0 x 11.9

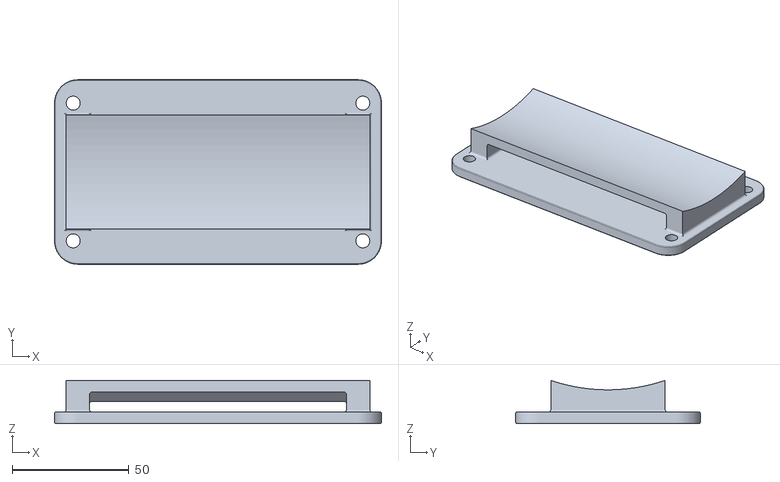
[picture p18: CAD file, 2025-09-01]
3d Prints/other/airlift tank manifold attachment.stl
140.0 x 79.0 x 18.6

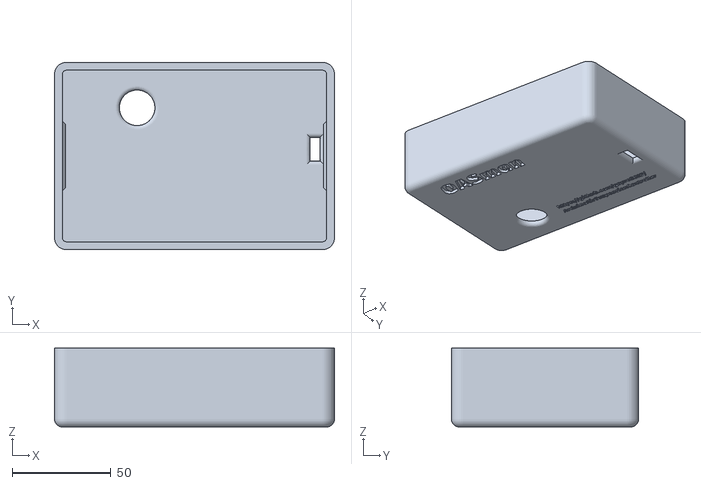
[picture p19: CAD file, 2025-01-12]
3d Prints/other/Box for pcb only/Snapfit PCB Lid.stl
142.0 x 95.0 x 40.0

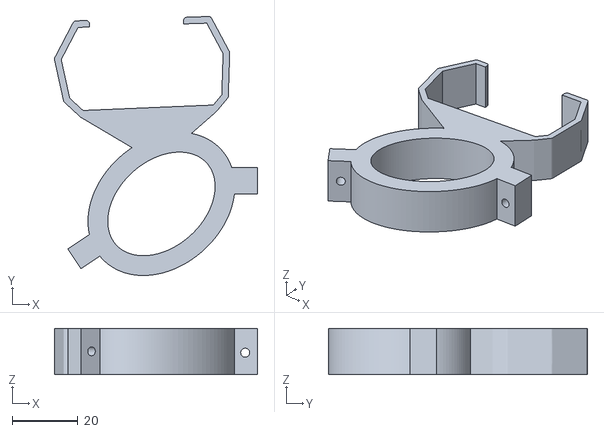
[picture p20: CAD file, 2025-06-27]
3d Prints/other/ps3 holder/ps3 holder v2_snug.stl
61.6 x 78.5 x 14.0

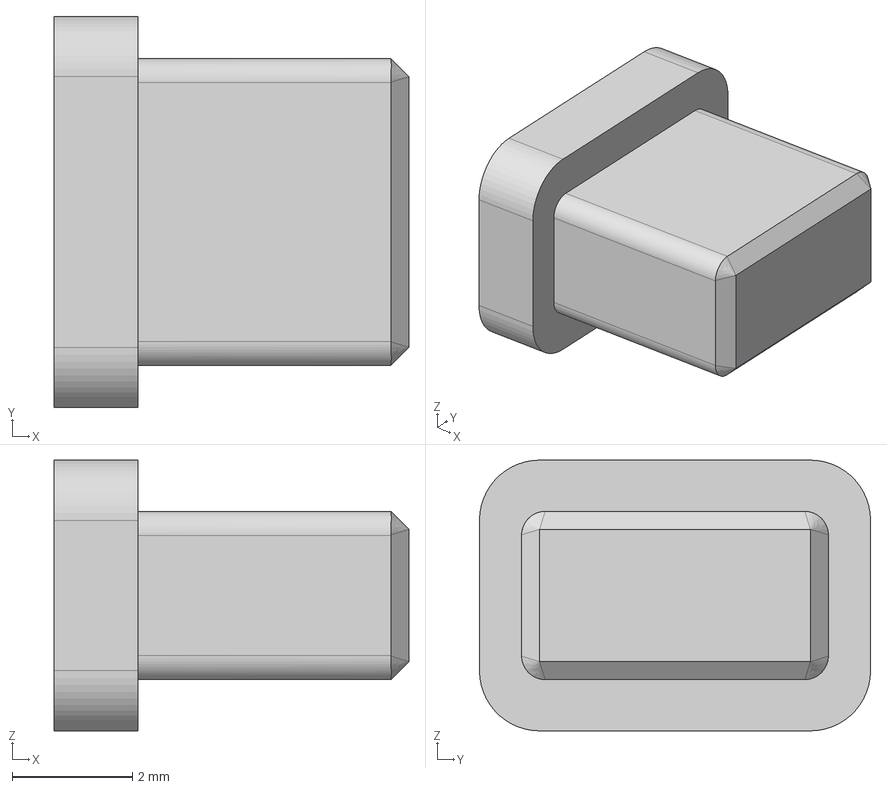
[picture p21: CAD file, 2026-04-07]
3d Prints/other/Waveshare 3.5 Faux Remix/Waveshare_3p5_Case_Button.step
5.90 x 6.50 x 4.50 mm

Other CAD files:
PCB/ESP32_30PIN_PCB/V2.4 (BAD DO NOT USE)/PCB_Esp32-Wroom-Air-suspension_2025-01-26.dxf
3d Prints/Waveshare 2.8 Controller (v37).stl
3d Prints/Manifold Base.stl
3d Prints/other/cup coaster/coaster.stl
3d Prints/Short Manifold Hat (no screen).stl
3d Prints/Short Manifold Lid (no pcb supports for extra room).stl
3d Prints/Tall Manifold Hat (no screen).stl
3d Prints/Tall Manifold Hat.stl
3d Prints/Tall Manifold Lid.stl
3d Prints/other/Waveshare 3.5 Faux Remix/Waveshare_3p5_Case.f3z
3d Prints/other/Waveshare 3.5 Faux Remix/Waveshare_3p5_Case.step
3d Prints/other/Waveshare 3.5 Faux Remix/Waveshare_3p5_Case.stl
3d Prints/other/Waveshare 3.5 Faux Remix/Waveshare_3p5_Case_Button.f3d
3d Prints/other/Waveshare 3.5 Faux Remix/Waveshare_3p5_Case_Button.stl
3d Prints/other/Waveshare_3p5_Itchyshaft/Waveshare_3p5_Case.step
3d Prints/other/Waveshare_3p5_Itchyshaft/Waveshare_3p5_Case.stl
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

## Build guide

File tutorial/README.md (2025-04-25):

# Tutorial

Documentation now lives on [oasman.dev](https://oasman.dev)

<!--
### Overview
Here is the official tutorial documentation on setting up your OAS-Man

### Sections
[Parts list](parts.md)<br>
[Assembling the pcb and wires](pcb_assembly.md)<br>
[Assembling the manifold](manifold_assembly.md)<br>
[Assembling the wireless controller](controller_assembly.md)<br>
[How to edit the code and flash the board](code_build_flash.md)<br>
[Android App](android_app.md)<br>
-->

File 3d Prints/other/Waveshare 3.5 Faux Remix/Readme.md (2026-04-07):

Waveshare_3p5_Case v9

Remix of Itchyshaft Waveshare 3.5 controller case. 
- Custom logo
- Slightly different tolerances 
- Changed USB C port
- Shortened button a smidge
- Meant for NO battery or a very small 3.7v cell under 50mm L x 12mm W x 6mm H. Unfortunately, most of them are quite low mAh, but it's an option.
- DXF file included for everyone's use. 

New Case is a Depth of 14.2mm, and it's probably already about as thin as it could get.

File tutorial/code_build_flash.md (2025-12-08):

# ESP32 Flashing Steps
### Quick Flashing
You can quickly and easily flash your main board and wireless controller through your web browser [here oasman.dev](https://oasman.dev/flash) <br>
If you wish to make any customizations to the code, please follow the following information below.
### Cloning the project code
1. Use git to clone the project normally. It is recommended you clone it and not download it, so that you can get future updates easily.
2. Here is what I recommend if you would like to easily clone the project, and what I will reference in the rest of this documentation:
    1. Dowload and install [github desktop](https://desktop.github.com/download/)
    2. Sign in to your github account
    3. Click clone project and clone `https://github.com/gopro2027/ArduinoAirSuspensionController.git`
    4. You can now choose branches, make your own local branches, pull updates, ect, all from within the GUI of github desktop
### Building and flashing
1. Download and install [visual studio code](https://code.visualstudio.com/)
2. In visual studio code go to extensions (4 cubes icon on lefthand bar) and install "PlatformIO IDE"
3. Open PlatformIO by clicking the alien icon on the lefthand bar and making sure it fully installs
4. Open the project:
    1. Double click the file `OASMan_ESP32.code-workspace` in `ArduinoAirSuspensionController/OASMan_ESP32/` and wait for all of the project dependencies to automatically download and install via platformio
    2. Tip: In github desktop at the top you can click `Repository` -> `Show in explorer` and then navigate into the folder `OASMan_ESP32` and you will see the file `OASMan_ESP32.code-workspace`
5. Build the project and test for errors:
    1. look in the top right corner and you should see a checkmark that says 'Build' when you hover over it. Click that and verify for no errors.
6. Install the project onto your esp32 by clicking the dropdown arrow next to the build button and choosing "Upload"

<!--
### Editing the code
1. In github desktop, create a new branch and call it `my_config` or whatever you want
2. Make edits.
3. Build and test your changes to make sure it is to your liking
4. Once you are finished with your edits, go back to github desktop and commit them to your `my_config` branch.
### Updating to the latest updates
1. Open github desktop
2. Select your `my_config` branch as your current branch or `main` if you have no custom configuration
3. Click `Fetch` in the top right
4. At the top click `Branch` -> `Update from main` and your code will be updated
5. If there is any merge conflicts you will need to fix them at this point. Feel free to ask the discord if you need help!
6. Now you can flash to your esp32 with the new update without loosing any custom configurations.

-->

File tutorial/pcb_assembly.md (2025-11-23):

# Wiring
### PCB assembly

The latest version of the PCB is SMD and intended to be assembled by the factory that assembles the PCB so no board assembly is required. Just place in the ESP32.<br>

<!--The pcb assembly is relatively straightforward when following as marked on the board.<br>
If you have any questions, please feel free to ask on the discord server.<br>
If you are wondering which soldering iron to use, I personally recommend using a TS100 soldering iron and some led solder.<br>
Here is a video of me assembling my 2.0 board, if you wish to follow along:<br>
<br>
[OAS-Man (Open Air Suspension Management) PCB Assembly<br>![OAS-Man (Open Air Suspension Management) PCB Assembly](https://github.com/user-attachments/assets/1cabc97b-822e-4c43-a45e-32a945192d54)](https://www.youtube.com/watch?v=XGFra2Tvlkg&ab_channel=gopro_2027)
<br> -->

### I/O Pin Wiring
For your main 6 pin i/o:<br>
For the power wires and compressor and auxillary wires you will want to use a 6 wire bundled 18 guage wire as listed in the parts<br>
Attach all 6 wires from the power connector, one to constant 12v battery, one to ground, and one to the accessory wire which turns on with the key<br>
Suggested / typical color coding:
- Red: 12v battery
- Black: ground
- Yellow: ACC
- White: Compressor
- Orange: Auxillary (Optional)
- Green: E-brake (Optional)

The compressor output should be wired to a relay as follows:
- Relay pin 86: Wire to the oasman board compressor output, 18 guage
- Relay pin 85: Wire to cars ACC wire (or constant 12v), 18 guage
- Relay pin 30: Wire to cars battery with a wire thich enough to handle the amps of the compressor.
- Relay pin 87: Wire to compressor positive wire.
Please make sure you have the proper fuses for the compressor and battery wires.

<sup>* Note: Although 85 typically goes to gnd, if we wired it this way the relays internal flyback diode dumps to the compressor and causes the compressor to briefly blip on upon shutdown. We instead wire it as mentioned above and utilize the oasman boards internal flyback diode to not cause this issue with the compressor.</sup><br>
<sup>See video [here](https://www.youtube.com/watch?v=QAD8vDHTbzo&ab_channel=WiringRescue) for additional wiring info on a negative triggered relay, where the oasman compressor output wire is acting as the switch in this video.</sup>

For the Auxillary wire, it is optional. But you would ideally connect it to a relay in the same manner that you could with the compressor output. You may use the auxillary wire to control anything you'd like from your wireless oasman controller, such as an electric water trap or a light bar. Completely optional though!

The e-brake wire is also optional. It should be connected so that when you pull the e-brake, this wire is connected directly to gnd.
<!-- Note to self: my car is this but im not sure it's correct even though it works: 86 goes to manifold compressor output, 85 goes to +12v battery, 30 to gnd, 87 to compressor -->
<br>



### Pressure and Height Sensor Wiring
Both the pressure and height sensors use 3 wires each. GND, 5V, and Data.<br>
Please attach 3 pin JST connectors to each so that they align with the same wires on the PCB.<br>
Obviously the height sensors are totally optional.<br>
If you are using the listed 5 sensor kit and choose to not cut off the oem connector and re-pin them to 3 pin, the board supports that too, it has a special connector (grey 8 pin connector in the pic below) just for compattability with this sensor kit. Just remember to run the pressure sensor detection after install to detect which sensors go to which wheels!<br>
<br>



### Manifold Wiring Harness Assembly (Valvetable)
#### Summary
The wiring was designed to be as easy as we could possibly make it. The pins on the PCB are 1 to 1 with the pins on the recommended manifold's connector. However, still, this is the most difficult part of the whole project so please pay attention, especially if you are running a different manifold.<br>
#### Brief overview
The board mimics the wires coming out of the manifold connector. If you imagine hanging the connector above the pcb, straightening out all the wires so they don't cross, then connecting them, that is the order in which the wires need to be connected.
The 3 top wires go in the same order on a 3 pin jst connector, and the 6 bottom wires go in the same order on a 6 pin jst connector. The only catch is to make sure you dont't accidentally put the connector upside down. <br>Simple?<br>Alright, lets get into the details...<br><br>
#### Detailed Tutorial
So the wiring harness is split up into 2 jst connectors, because it's a 2x6 connector but 3 of the pins are not used.<br>
So on the one half with the 3 pins in a row and 3 unused pins, we will connect them to a 3 pin jst connector in the same order (no crossed wires) as so:<br>
<br>
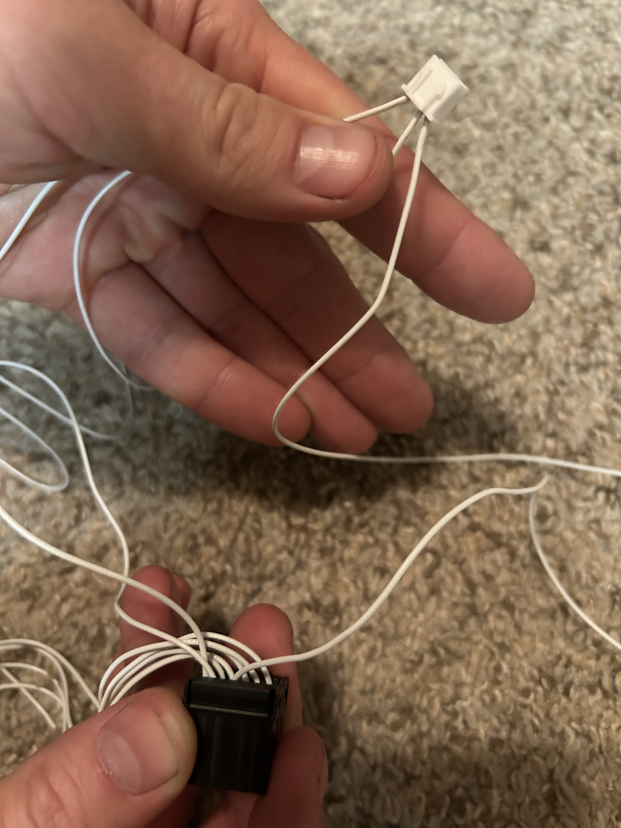
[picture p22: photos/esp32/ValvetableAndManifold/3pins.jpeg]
3 pin on manifold harness
<br>
<br>
Please note the orientation of the connectors so that you don't accidentally have the order flipped. You want to make sure the connector on the board connects to the wires in the same order and not upside down. If you follow exactly as the pictures on this page show, you should be fine.<br>
You can double check all of the wiring by cross referencing the information supplied in the images following and labels on the PCB.<br>
The other half of the harness is 6 pins in a row, so we will connect all 6 to a 6 pin jst connector, also in the same order with no wires crossed. Again making sure to not have the connector upside down in respect to how you have it soldered on the board.<br>
<br>
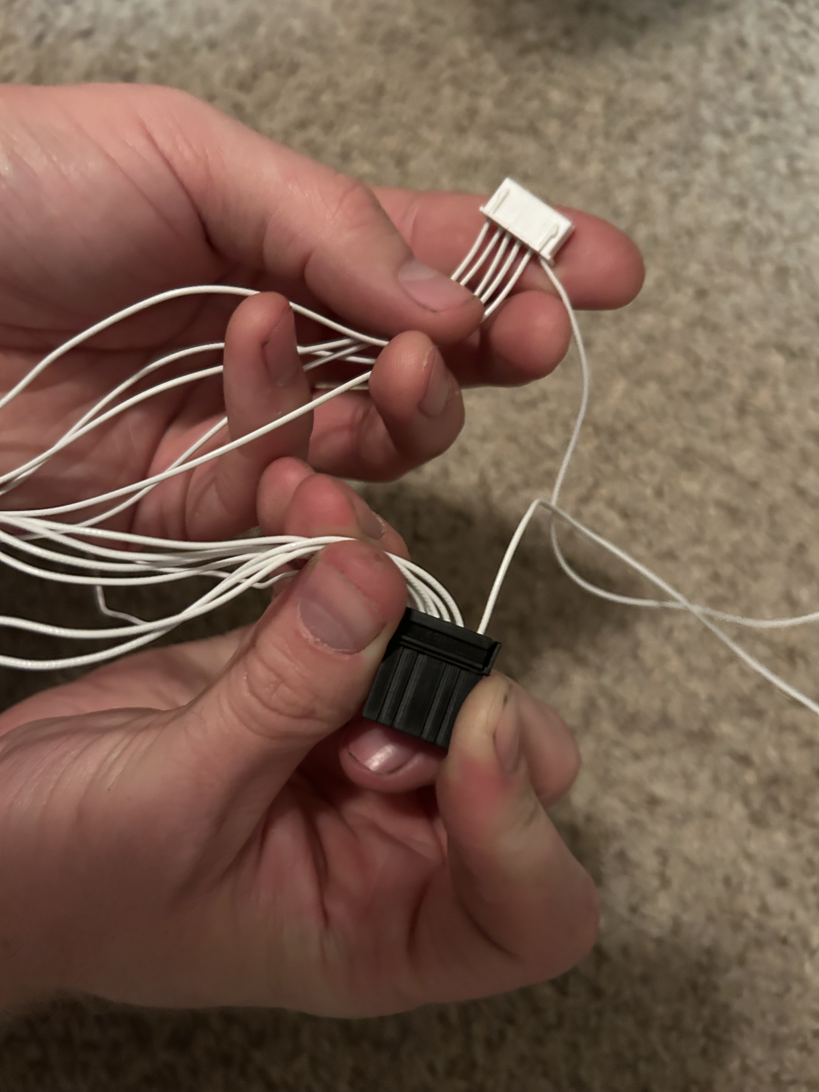
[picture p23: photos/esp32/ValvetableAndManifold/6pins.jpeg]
6 pin on manifold harness
<br>
<br>
You can see for example how the #6 pin on the pinout is connected to the spot that will plug into the RDO on the PCB from the image shown next.<br>
If attached as shown in the video, they should connect to the board with the other side of the jst connector in this orientation:<br>
<br>
valvetable jst orientation on board<br>
<br>
<br>
Here is the full pinout of wiring harness that comes with the manifold for a full cross reference:<br>
<sub>* Note that this is looking into the connector from the female side, with the holes</sub><br>
<br>
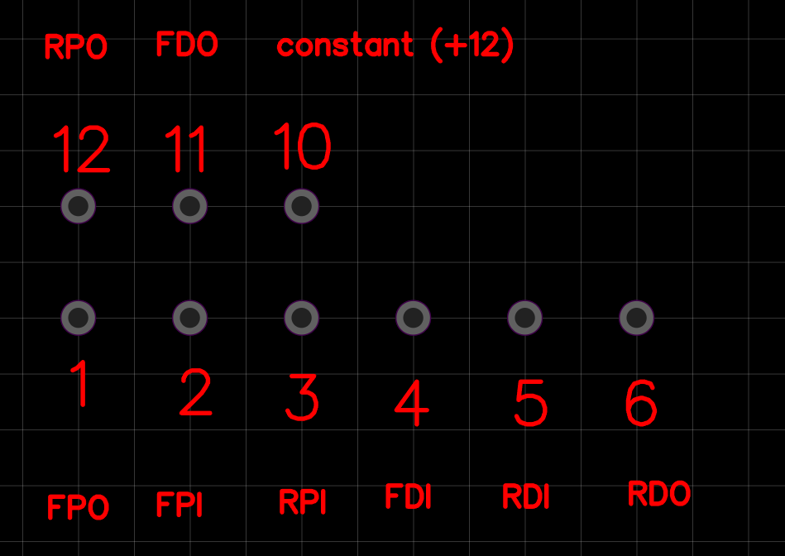
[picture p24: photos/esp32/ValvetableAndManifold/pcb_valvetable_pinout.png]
manifold connector wiring cross reference
<br>
<br>
And here is my annotated documentation that may also be of use for a double check:<br>
<sub>* Note that this is looking into the connector from the male side, with the wires</sub><br>
<br>
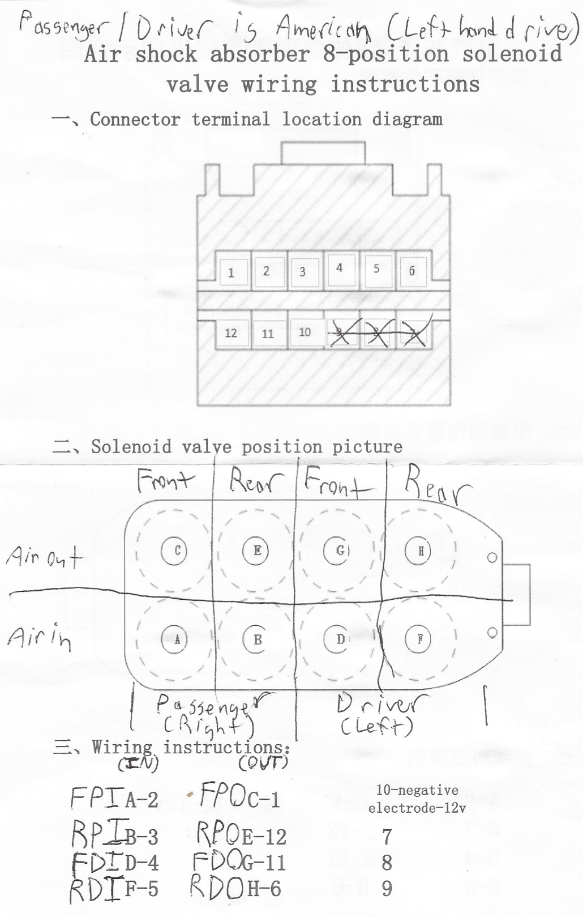
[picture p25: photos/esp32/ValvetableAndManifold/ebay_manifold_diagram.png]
manifold documentation annotated
<br>
<br>
The final result will look something like this:<br>
<br>
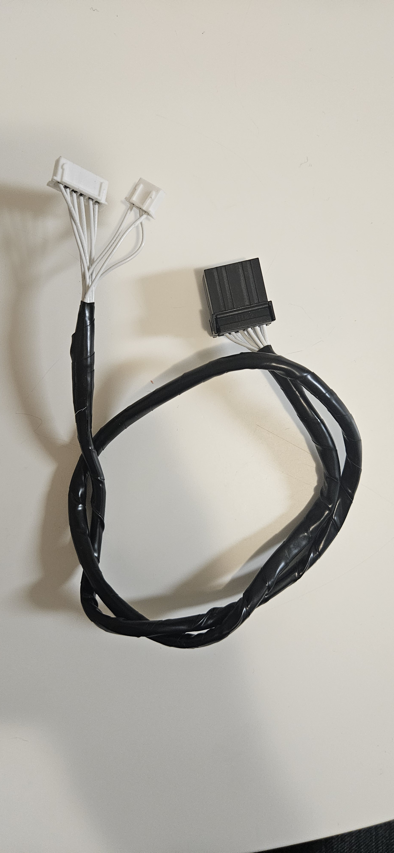
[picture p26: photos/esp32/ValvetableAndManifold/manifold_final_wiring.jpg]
wiring harness final result
<br>
<br>
After completing all the jst connectors, I put hot glue on the ends of them to keep the wires from being stressed too much when moved around and assembled:<br>
<br>
<br>

### Congratulations on assembling the wiring!

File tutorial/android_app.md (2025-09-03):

# Mobile App

Our android/ios app is written in the flutter SDK.

Currently it is not released for IOS yet, but you can download and install the APK manually on andorid.

You can find the latest APK files in this folder [here](https://github.com/gopro2027/ArduinoAirSuspensionController/tree/main/builds/Android)

As of 9/3/2025, the app just has basic functionality just to help you get your car up if you happen to forget your controller or something, but eventually it will have all the same functionality as the mobile controller.

Huge shoutout to our app devs, mustafa1234 and Efini in the discord server for their work on the mobile app, while I focus on other aspects of the project. Thanks guys!

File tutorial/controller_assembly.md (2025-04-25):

# Controller assembly
Not much assembly required.<br>
Print out the case in a material like PETG. I recommend using a carbon fiber texture board personally for aesthetics.<br>
Purchase your ESP32-2432S032C and battery. If you get the wrong cable on the battery, my ESP32-2432S032C came with the correct battery cable so yours probably will too. Solder that one on.<br>
You can use double sided tape to attach the battery to the back panel of the case or to the back of the board.<br>
Screw the case on with M3 screws.<br>

rn_image_picker_lib_temp_0c41e8e4-817b-480f-a613-8afa0c4c94a8 (1)

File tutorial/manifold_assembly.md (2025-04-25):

# Manifold Assemmbly

Get the 3d prints to print from [here](https://github.com/gopro2027/ArduinoAirSuspensionController/tree/main/3d%20Prints)<br>
There are 2 versions, Tall and Short. The tall version is standard with good room for everything to fit well inside of it. The short is 2cm shorter, does not fit the lcd screen, and is there just because, but is not particularly recommended. Required to put something like foam padding between the pcb and the manifold if you use the short version.<br>
Print them in a plastic with medium-high heat resistance such as PETG or ABS<br>
Print the lid upside down.<br>
For the hat please choose the version with or without the screen. Print upright<br>
The base prints upright<br>
<br>
You can attach the screen to the 3d printed hat with m2 screws. More info below.<br>
You can attach the pcb board to the 3d printed lid with m3 screws.<br>
<br>
On the manifold:<br>port 1 goes to front passenger (right)<br>port 2 goes to rear passenger (right)<br>port 3 goes to front driver (left)<br>port 4 goes to rear driver (left)<br>



The ports on the opposite side will correspond to the pressure sensors for the same bags. **Note:** If you are unsure which pressure sensor goes to which, just install them in any order and run the pressure sensor detection upon first startup.<br>
Please see the annotated diagram for a full breakdown<br>

diagram<br>
3d render
physical pic

<br>
If you intend to utilize the built in lcd screen, follow these instructions:<br>
Solder the 4 wires and jst connector properly so that the wire names match the board.<br>
Loosely snug down the screen to the manifold, emphasis on loosely! Just barely snug. The screens are very fragile, particularly on the lower 2 corners of the screen.<br>
Once the screen is positioned, put some dabs of super glue on the inside nuts to hold it in place.<br>
Please note that when using the screen you will need to slightly bend back some of the mosfets in order to not have them touch the screen.<br>
<br>

lcd screen<br>
<br>
To finish up the install, use the scews and nuts supplied with the manifold to screw it all to the 3d printed base.<br>
You can place the 4 nuts into the base and then screw them down through the top.<br>
Please only snug it enough as to not break any of the plastic.<br>
* Note if you are assembling the short version: I have become aware of an issue where the force to screw through the o-ring in the nut is enough to damage the plastic (PETG) in the base and spin the nut. This was fixed in the tall version by making it 0.5mm thicker. This was not fixed in the short version as it is an older model, so just take extra precaution when screwing it down to not damage it.<br>
<br>

final build<br>
<br>

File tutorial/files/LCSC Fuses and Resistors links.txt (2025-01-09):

LCSC parts:
PTF-77: https://www.lcsc.com/product-detail/Fuseholders_XFCN-PTF-77_C717030.html
Fuse: https://www.lcsc.com/product-detail/Disposable-fuses_Reomax-STC1300_C5381727.html
10K: https://www.lcsc.com/product-detail/Through-Hole-Resistors_VO-MF1-4W-10K-1-ST52_C2903232.html
150R: https://www.lcsc.com/product-detail/Through-Hole-Resistors_VO-MF1-4W-150-1-ST52_C2903242.html
2K: https://www.lcsc.com/product-detail/Through-Hole-Resistors_VO-MF1-4W-2K-1-ST52_C2903278.html
1K: https://www.lcsc.com/product-detail/Through-Hole-Resistors_VO-MF1-4W-1K-1-ST52_C2903245.html
1N4007 Diode: https://www.lcsc.com/product-detail/Diodes-General-Purpose_Yangzhou-Yangjie-Elec-Tech-1N4007_C2986225.html

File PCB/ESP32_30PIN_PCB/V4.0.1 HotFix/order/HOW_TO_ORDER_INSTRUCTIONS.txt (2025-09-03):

Instructions:

(numbers calculates pre-tariff on a v3 board)

NOTE BEFORE YOU ORDER: ASK IN THE DISCORD FIRST IF ANYONE HAS SOME FOR SALE FOR CHEAPER BECAUSE MOST PEOPLE DON'T NEED ALL THE ONES JLCPCB WILL SEND (BULK ORDERS ONLY). ORDERING FROM JLCPCB IS MINIMUM OF 5 BOARDS AND A LITTLE OVER $100 AFTER SHIPPING (about $120 for 5 full PCBA, or about $14 less ($106) if you only get 2 boards assembled)

Go to jlcpcb.com
Upload gerber file Gerber_PCB1_3_2025-03-03.zip
Choose PCB color of your choice
Choose how many to order (recommended default minimum of 5)
Select the button to enable PCB Assembly (PCBA)
Choose how many to have assembled (recommended 5 instead of minimum of 2, price difference is only $14)
Click NEXT button
You are on the PCB page, click NEXT again
You are on the Bill of Materials page:
	Click add BOM file button and choose BOM_SMD test 2_PCB1____.xlsx
	Click add CPL file button and choose PickAndPlace_PCB1____.xlsx
Click Process BOM & CPL button. Verify stock and modify if they are out of stock (hopefully not!)
Click next and verify positioning (should be fine) click next again
Click save to cart button and go to check out and choose shipping.
* (Recommended) UPS express saver seems to be the best overall for the price ($27.77)
* Global standard direct line is the cheapest but will take ages to receive ($13.29)
* The others tend to be inferior in price and speed
Complete purchase?

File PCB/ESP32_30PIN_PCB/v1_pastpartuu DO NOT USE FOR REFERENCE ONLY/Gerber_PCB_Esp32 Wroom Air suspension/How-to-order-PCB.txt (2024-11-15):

How to Order PCB

Please refer to:
https://docs.easyeda.com/en/PCB/Order-PCB

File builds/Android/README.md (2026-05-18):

Android builds are no longer posted here. They are now published to the play store:
https://play.google.com/store/apps/details?id=dev.oasman.oasman_mobile

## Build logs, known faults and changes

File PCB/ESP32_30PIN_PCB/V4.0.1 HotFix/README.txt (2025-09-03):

v4.0
Converted to 4 layer board
switched to microfit fittings
added auxillary output and e brake input to board

Credits: Bw

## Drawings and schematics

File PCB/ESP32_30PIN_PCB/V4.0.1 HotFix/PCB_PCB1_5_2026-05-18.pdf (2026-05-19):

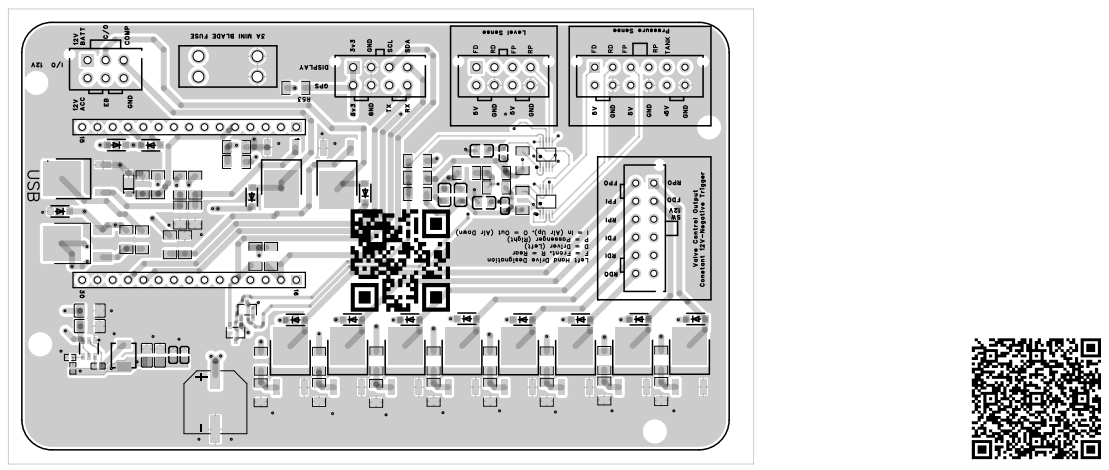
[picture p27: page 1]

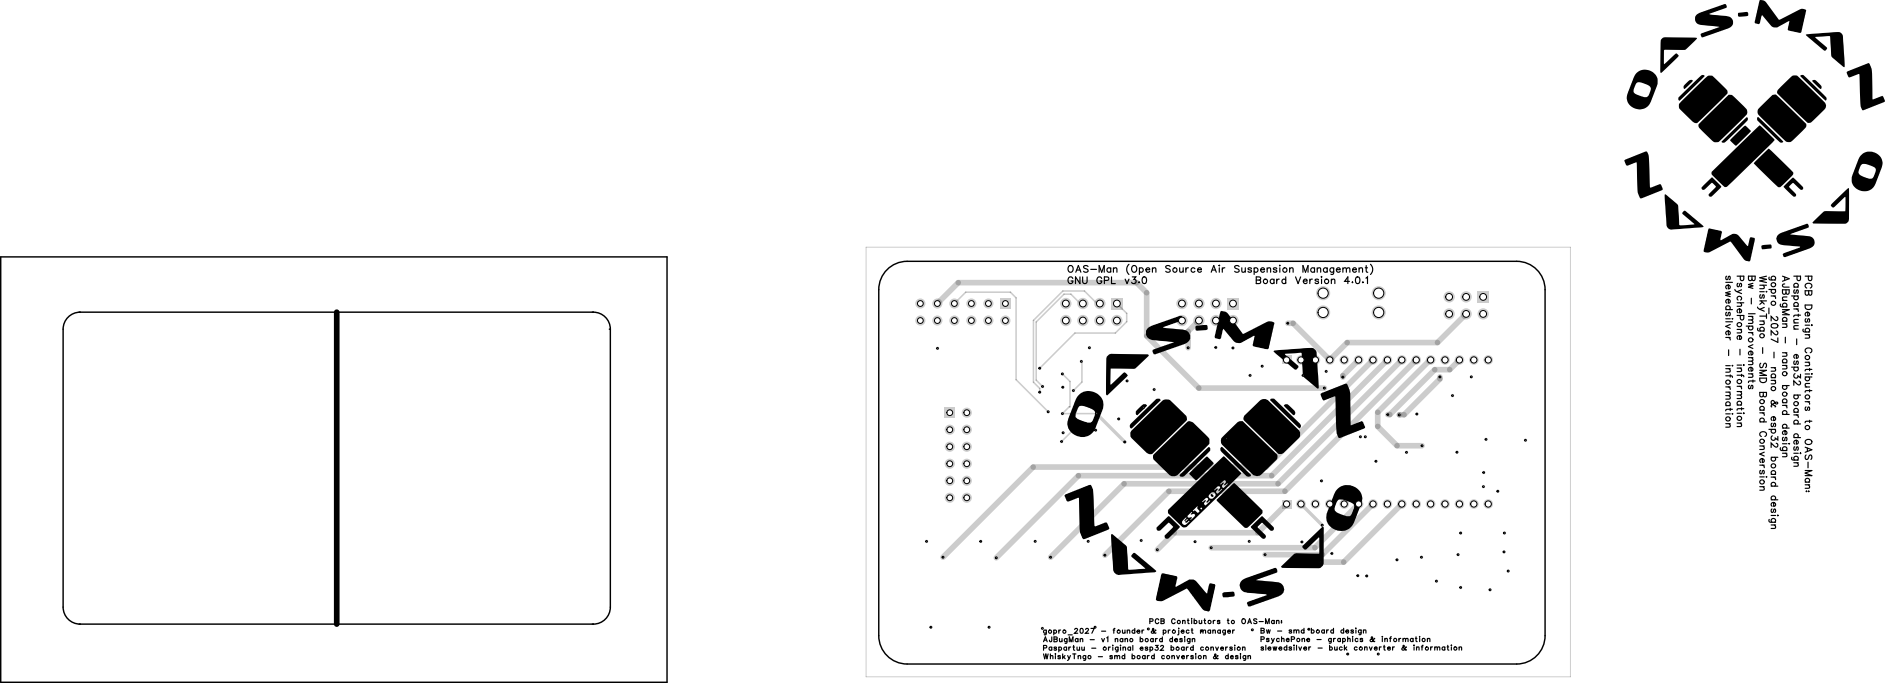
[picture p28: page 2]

OAS-Man (Open Source Air Suspension Management)

WhiskyTngo - SMD Board Conversion

AJBugMan - nano board design

PCB Design Contibutors to OAS-Man:

gopro_2027 - founder & project manager
AJBugMan - v1 nano board design
Paspartuu - original esp32 board conversion
WhiskyTngo - smd board conversion & design

PCB Contibutors to OAS-Man:

Bw - smd board design
PsychePone - graphics & information
slewedsilver - buck converter & information

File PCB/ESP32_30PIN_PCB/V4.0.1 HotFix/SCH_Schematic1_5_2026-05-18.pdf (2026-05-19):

# Main Power Switch

# 2x ADS1115 circuitry (Pressure & level sensors)

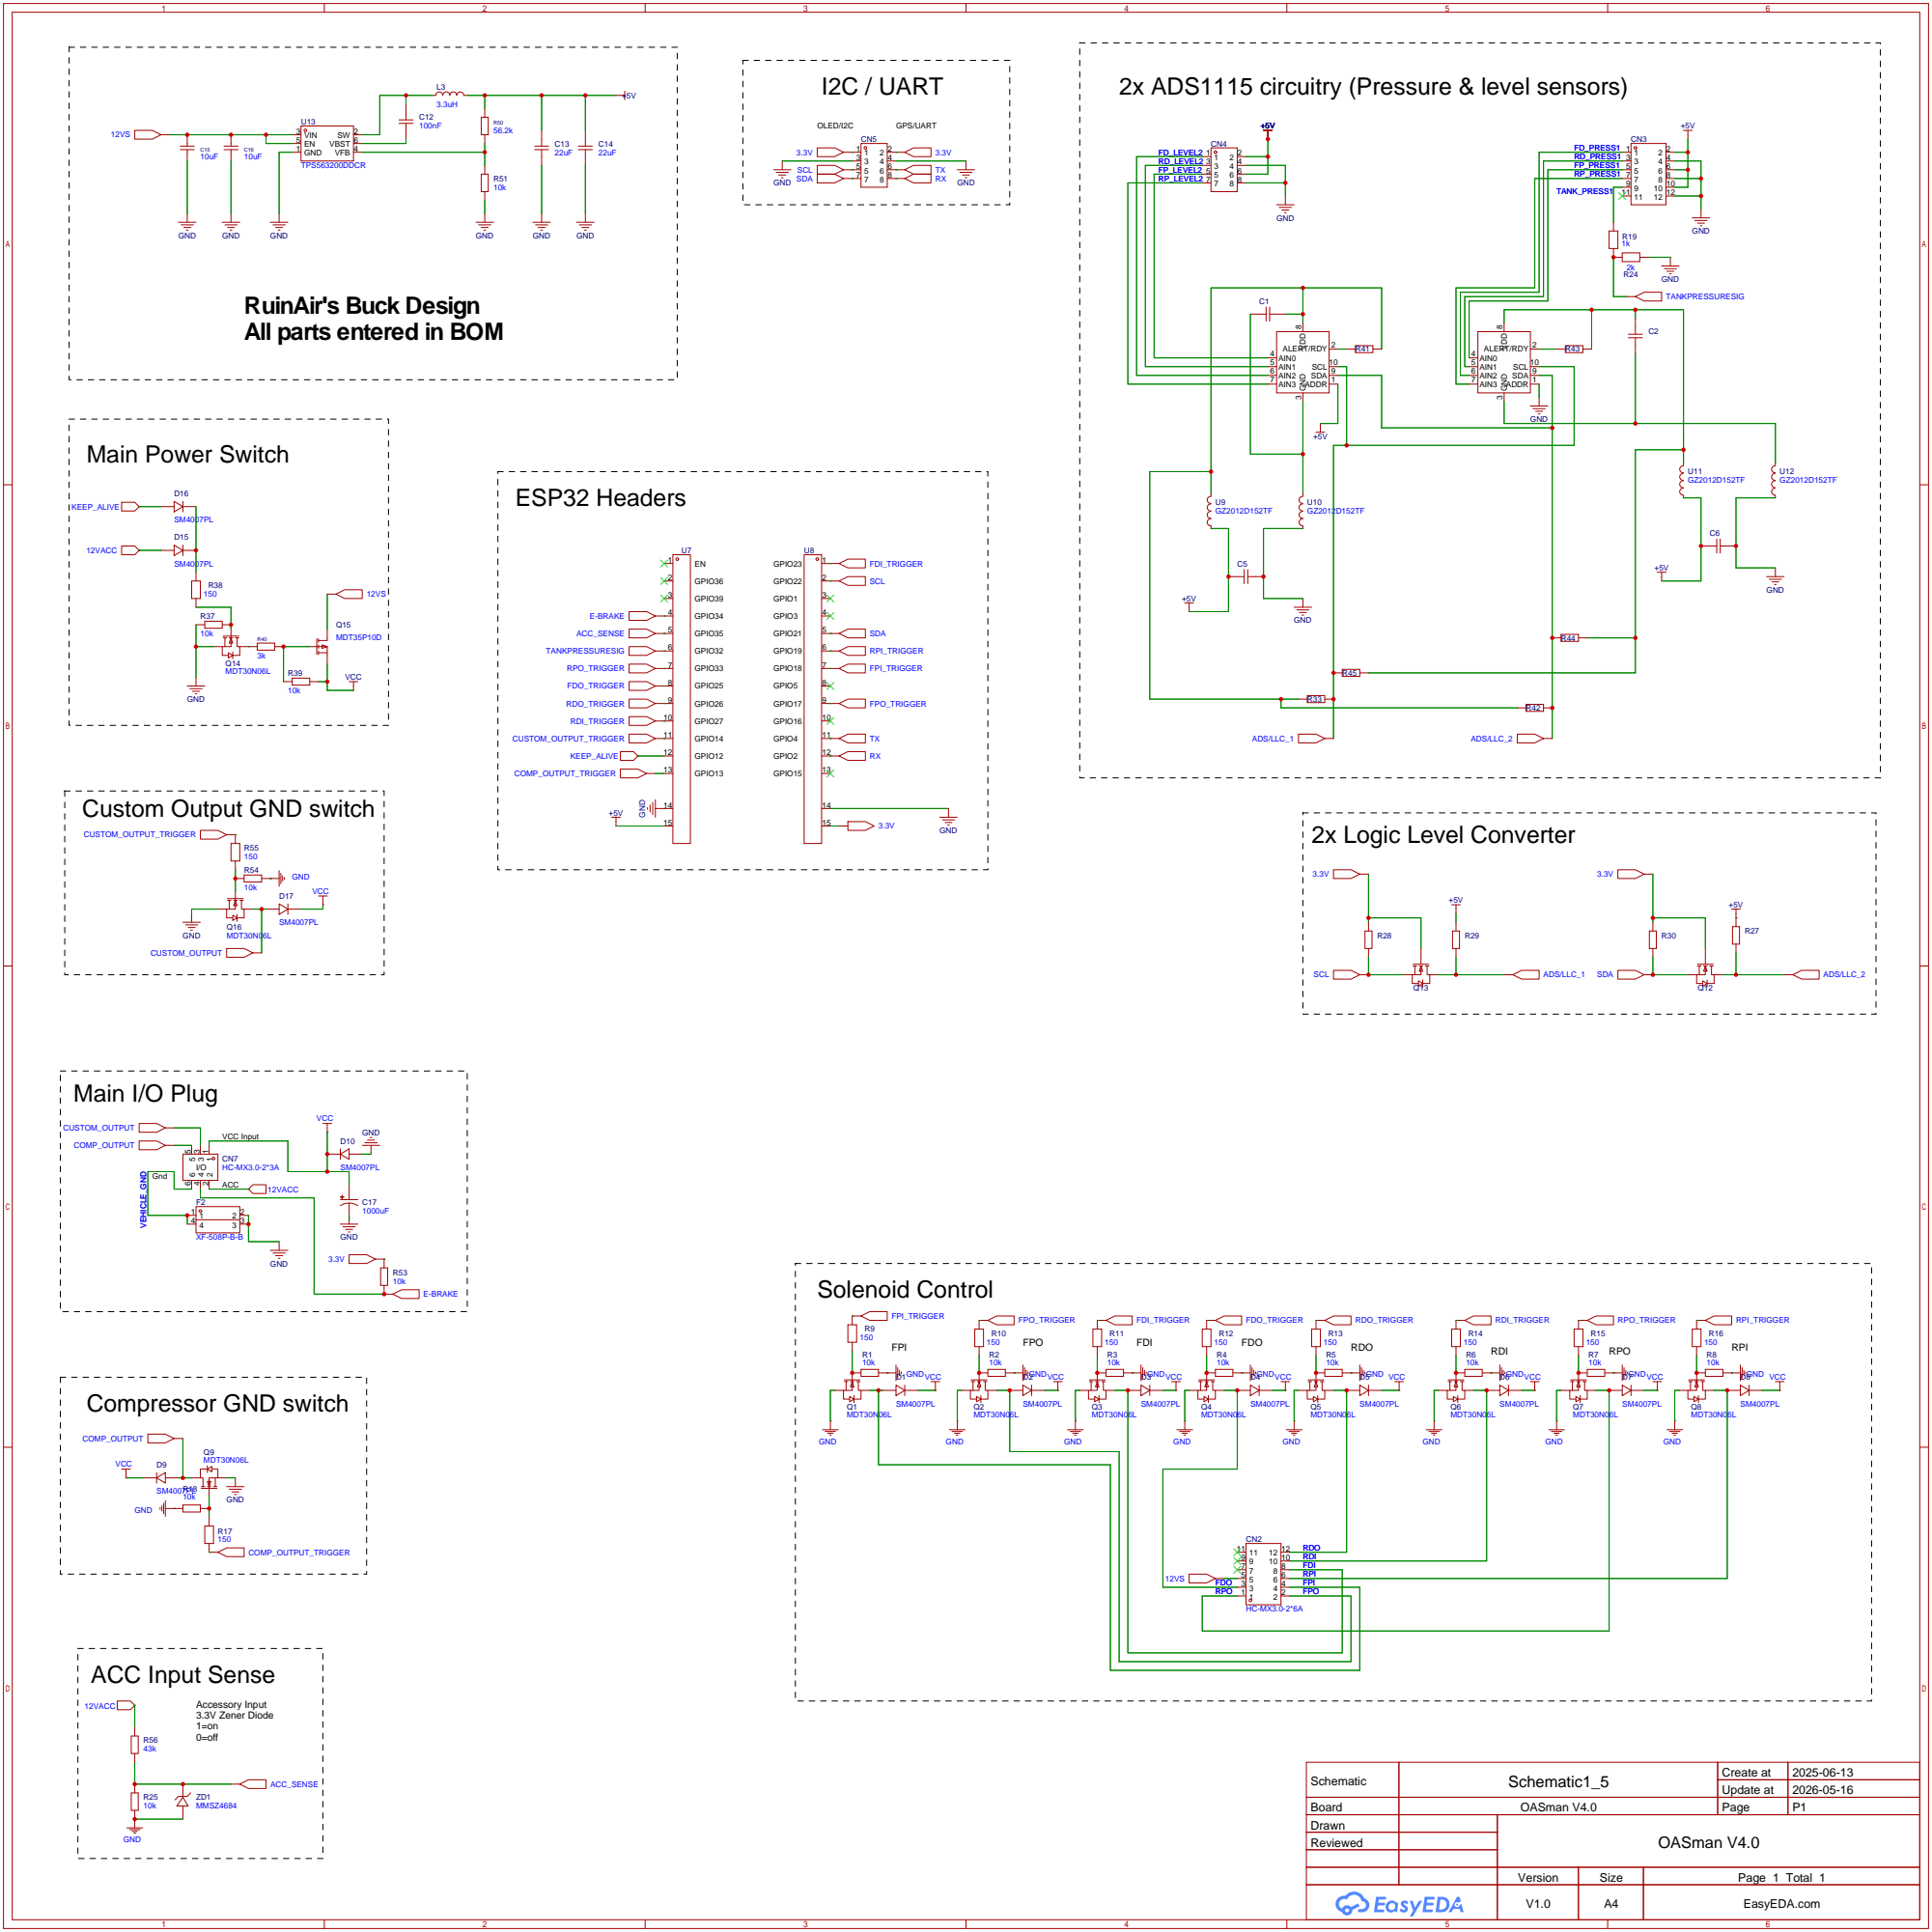
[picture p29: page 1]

RuinAir's Buck Design
All parts entered in BOM

Custom Output GND switch

Schematic | Schematic1_5 | Create at | 2025-06-13

Update at | 2026-05-16

Board | OASman V4.0 | Page | P1
Drawn | | OASman V4.0
Reviewed

Version | Size | Page 1 Total 1
V1.0 | A4 | EasyEDA.com

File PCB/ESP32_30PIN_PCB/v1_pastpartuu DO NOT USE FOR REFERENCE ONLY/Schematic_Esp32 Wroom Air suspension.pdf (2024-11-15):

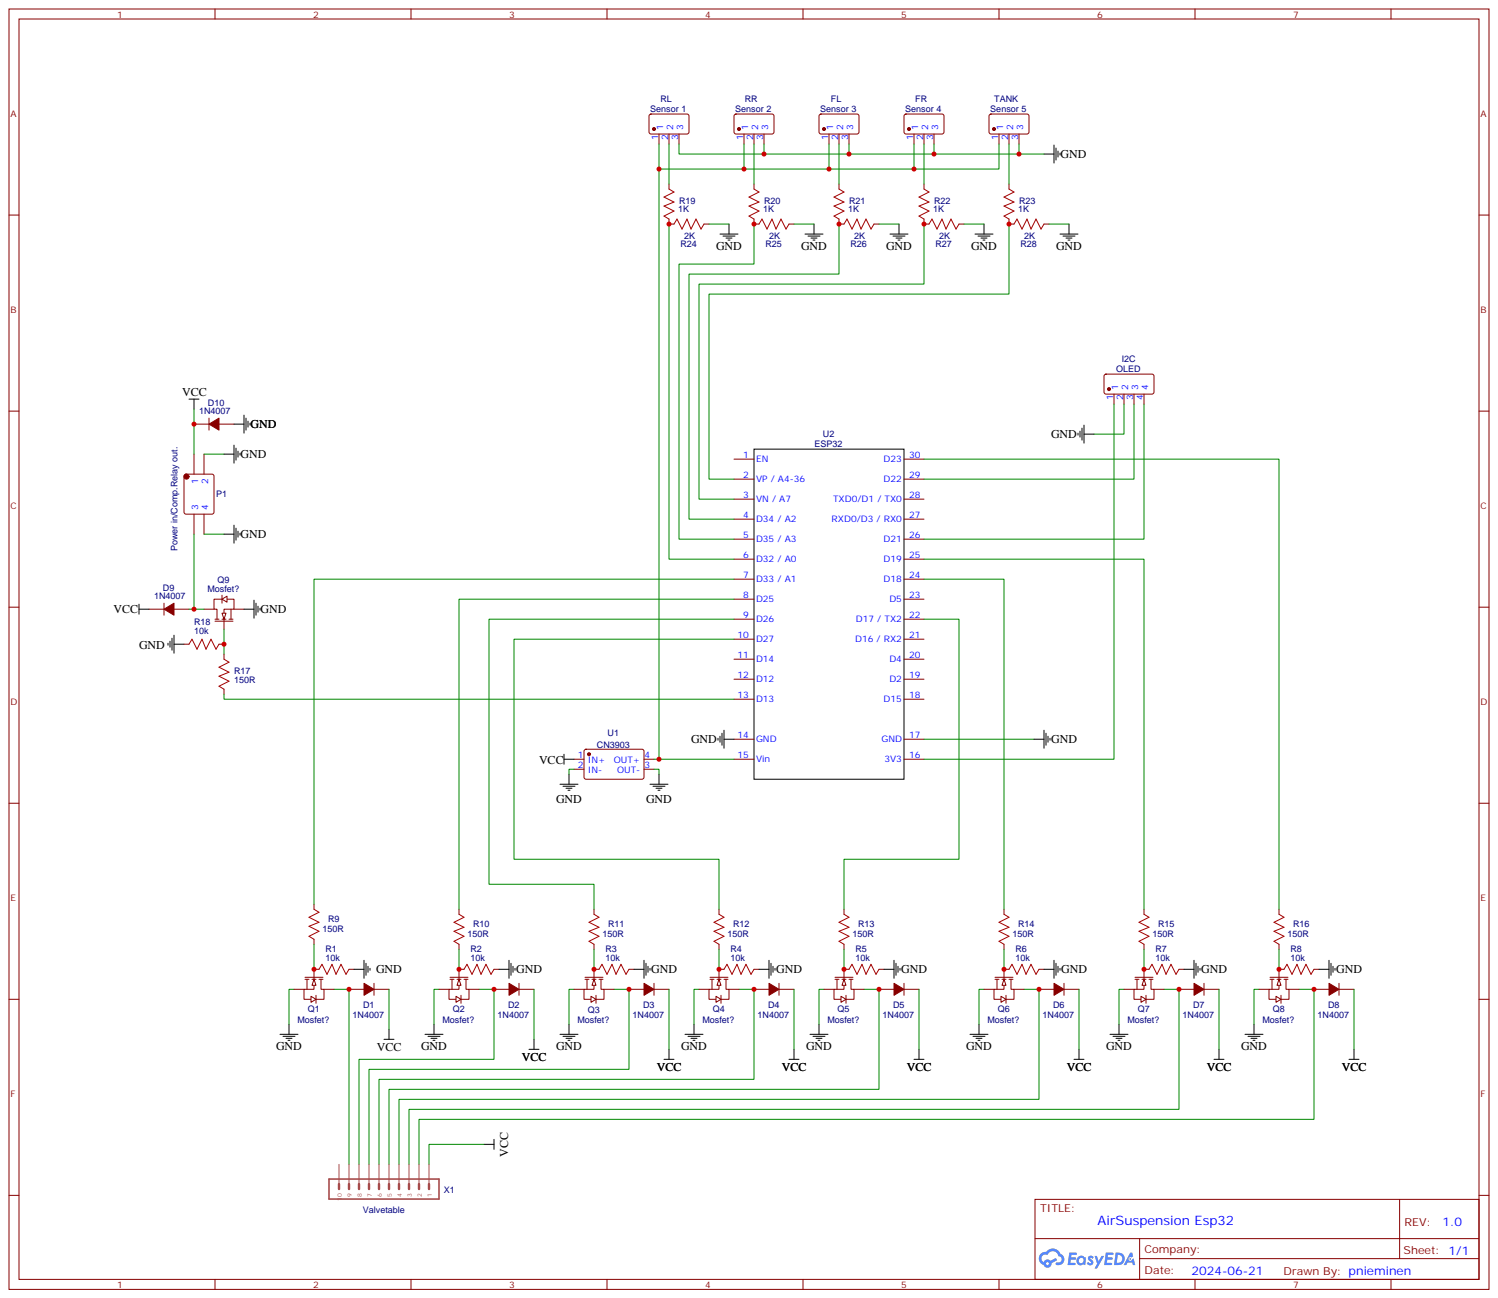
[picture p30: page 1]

Power in/Comp.Relay out.

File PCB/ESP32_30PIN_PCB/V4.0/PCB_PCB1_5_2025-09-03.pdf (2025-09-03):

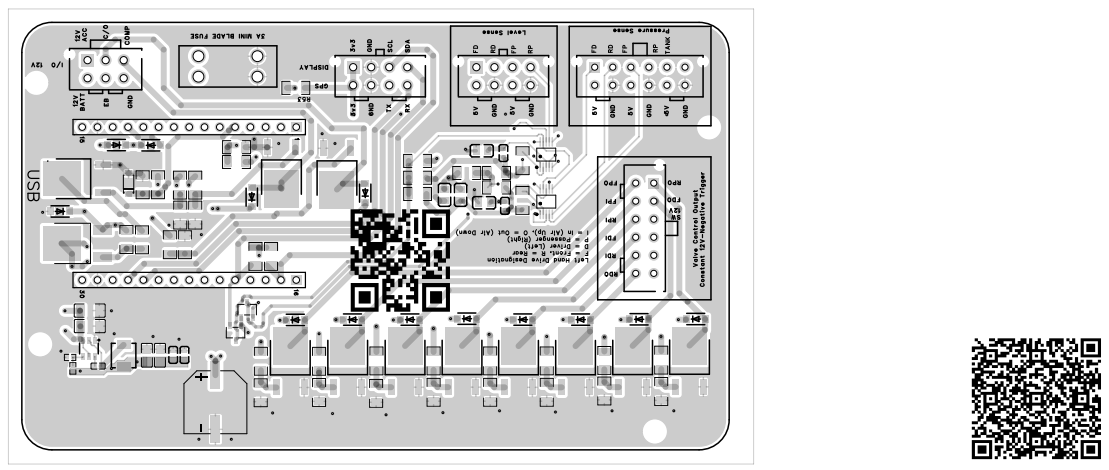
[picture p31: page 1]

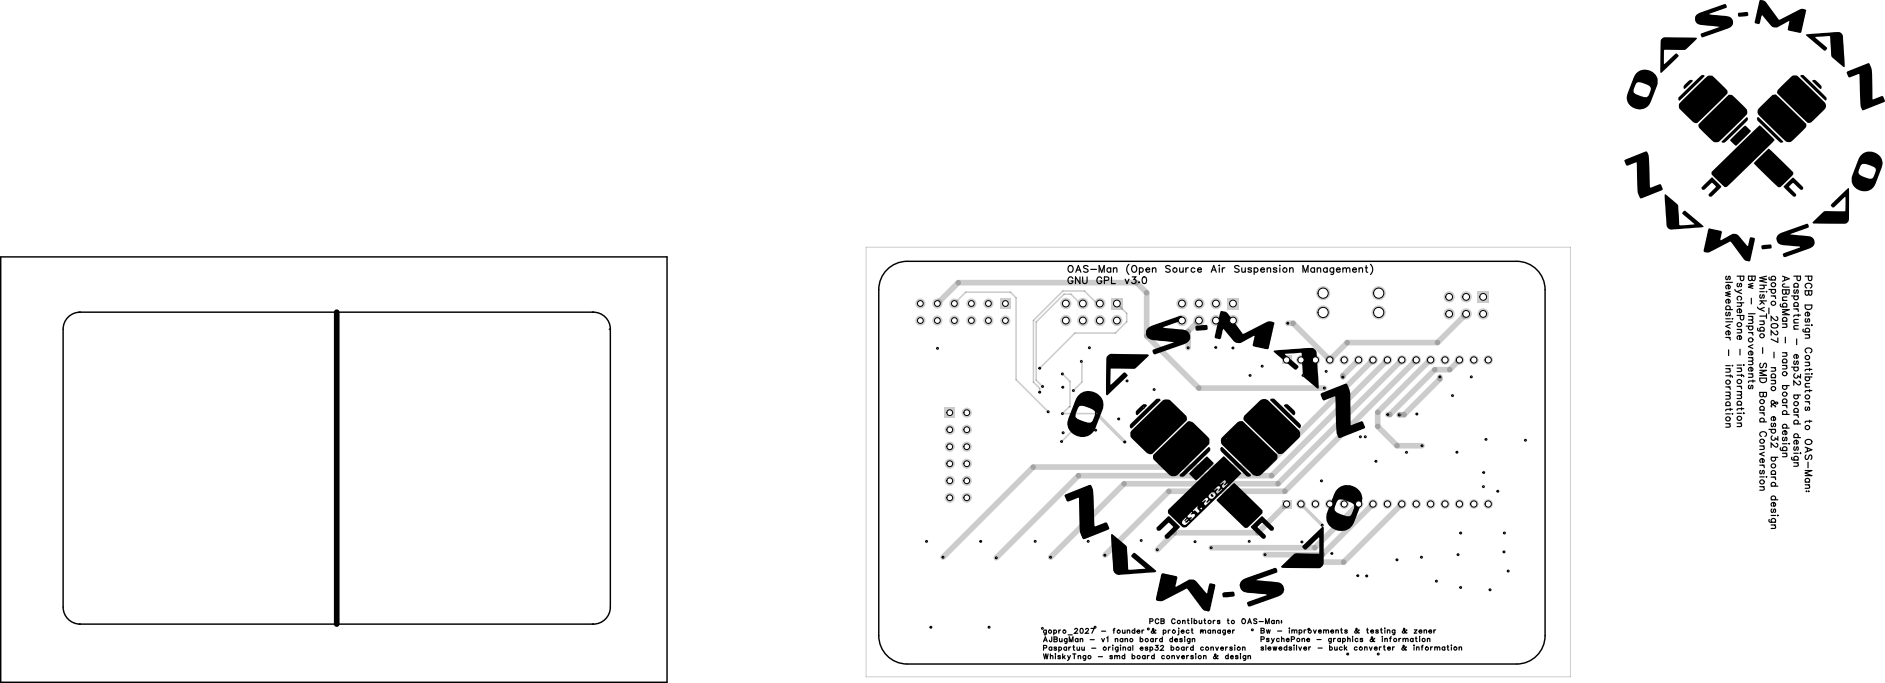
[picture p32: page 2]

OAS-Man (Open Source Air Suspension Management)
GNU GPL v3.0

WhiskyTngo - SMD Board Conversion

AJBugMan - nano board design

PCB Design Contibutors to OAS-Man:

gopro_2027 - founder & project manager
AJBugMan - v1 nano board design
Paspartuu - original esp32 board conversion
WhiskyTngo - smd board conversion & design

PCB Contibutors to OAS-Man:

Bw - improvements & testing & zener
PsychePone - graphics & information
slewedsilver - buck converter & information

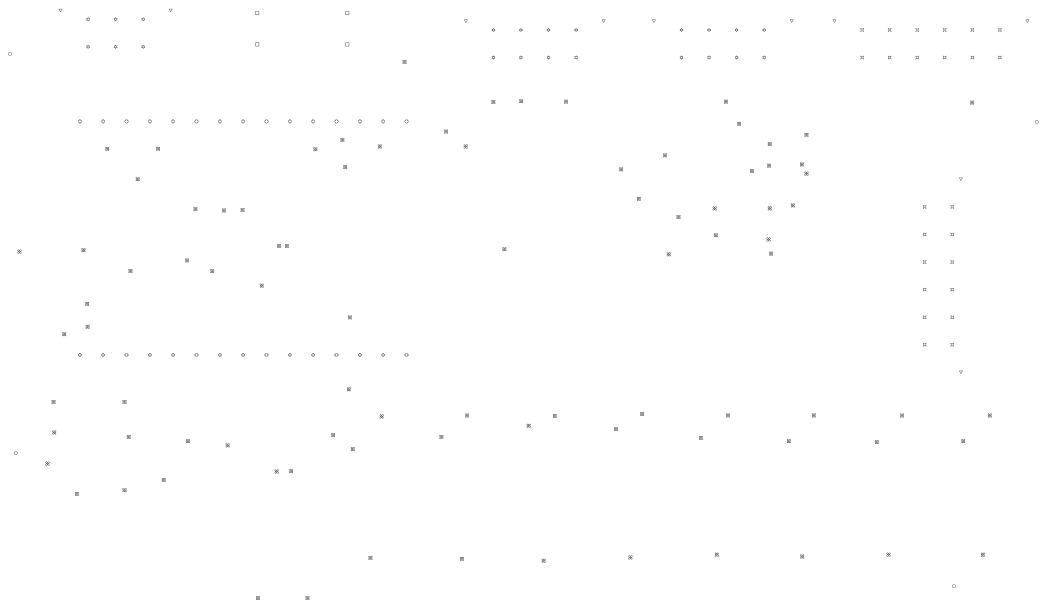
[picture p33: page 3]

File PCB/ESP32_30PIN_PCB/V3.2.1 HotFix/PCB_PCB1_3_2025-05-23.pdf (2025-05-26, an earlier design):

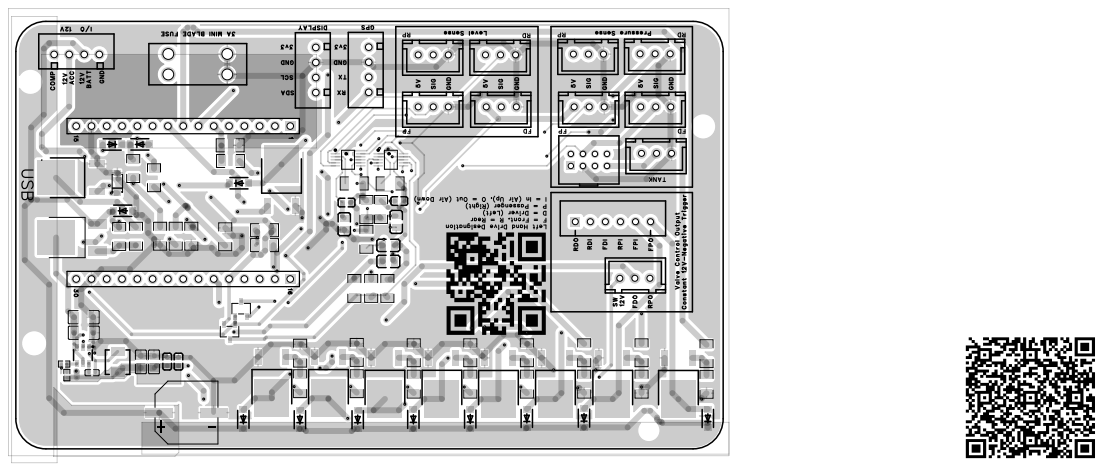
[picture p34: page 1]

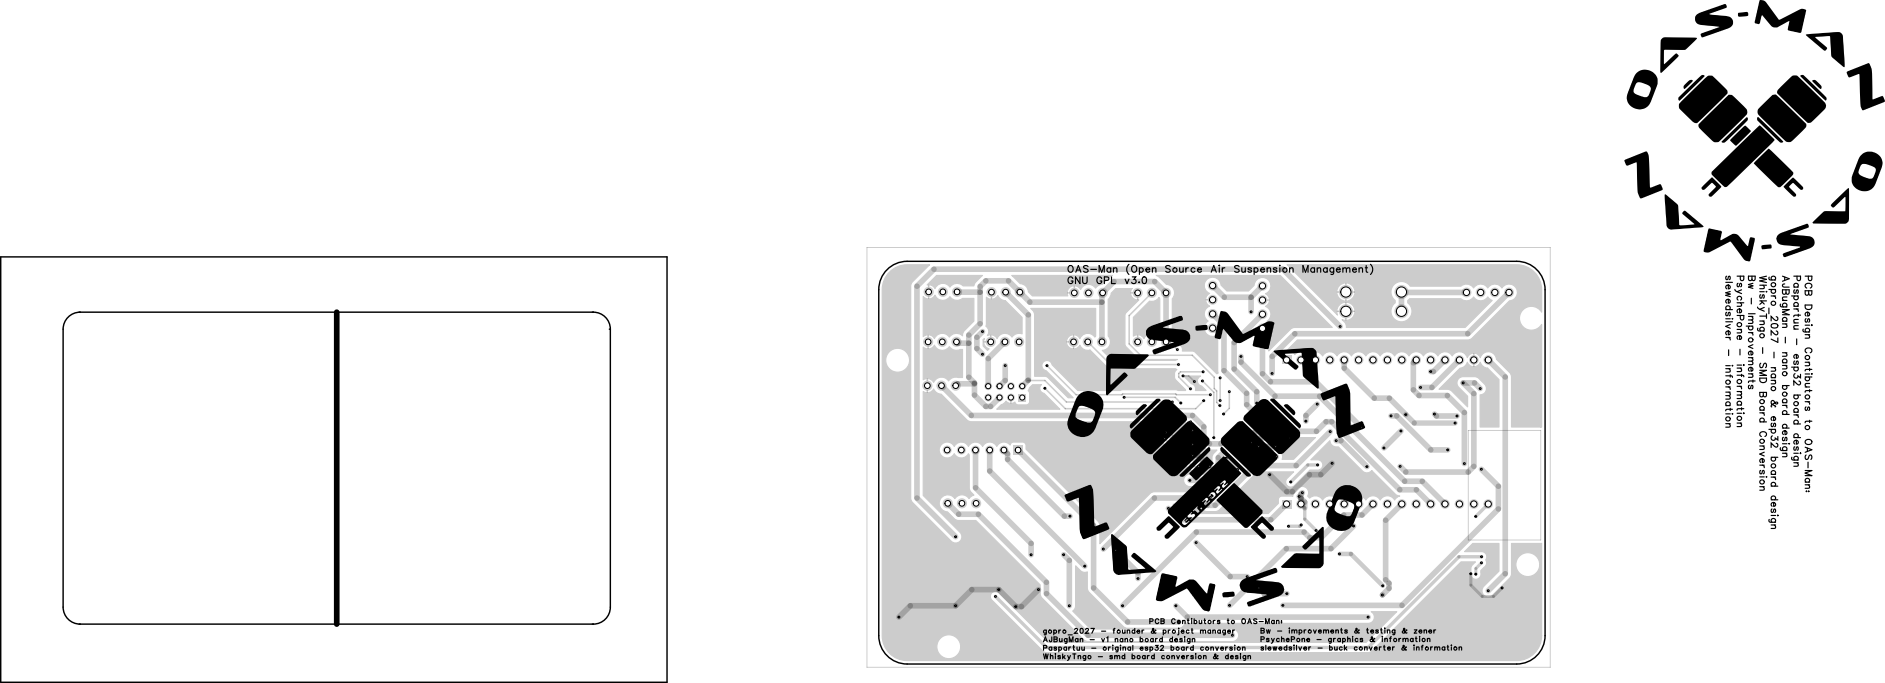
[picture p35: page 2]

OAS-Man (Open Source Air Suspension Management)
GNU GPL v3.0

WhiskyTngo - SMD Board Conversion

AJBugMan - nano board design

PCB Design Contibutors to OAS-Man:

gopro_2027 - founder & project manager
AJBugMan - v1 nano board design
Paspartuu - original esp32 board conversion
WhiskyTngo - smd board conversion & design

PCB Contibutors to OAS-Man:

Bw - improvements & testing & zener
PsychePone - graphics & information
slewedsilver - buck converter & information

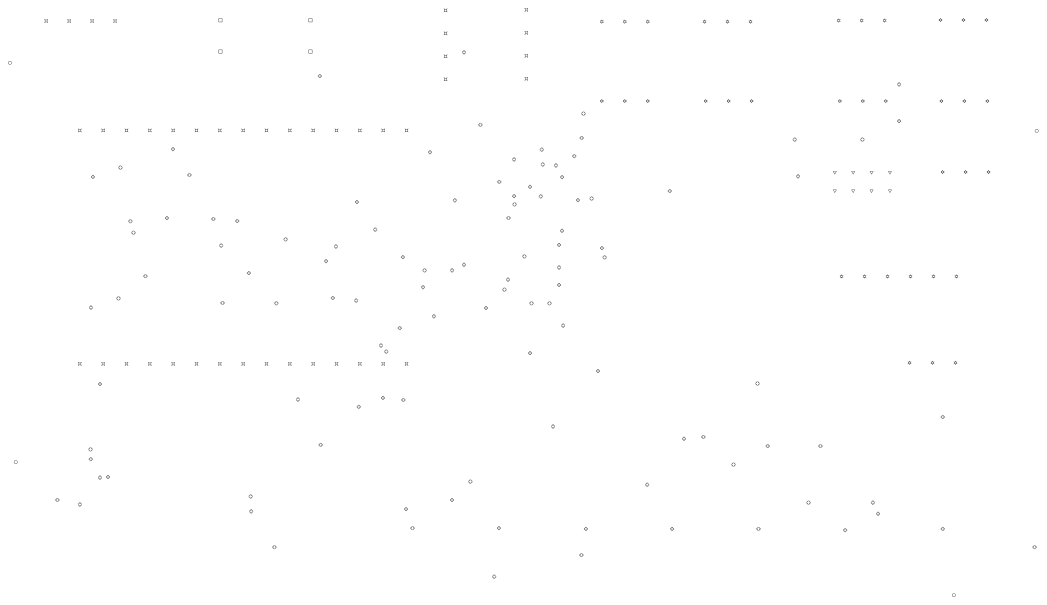
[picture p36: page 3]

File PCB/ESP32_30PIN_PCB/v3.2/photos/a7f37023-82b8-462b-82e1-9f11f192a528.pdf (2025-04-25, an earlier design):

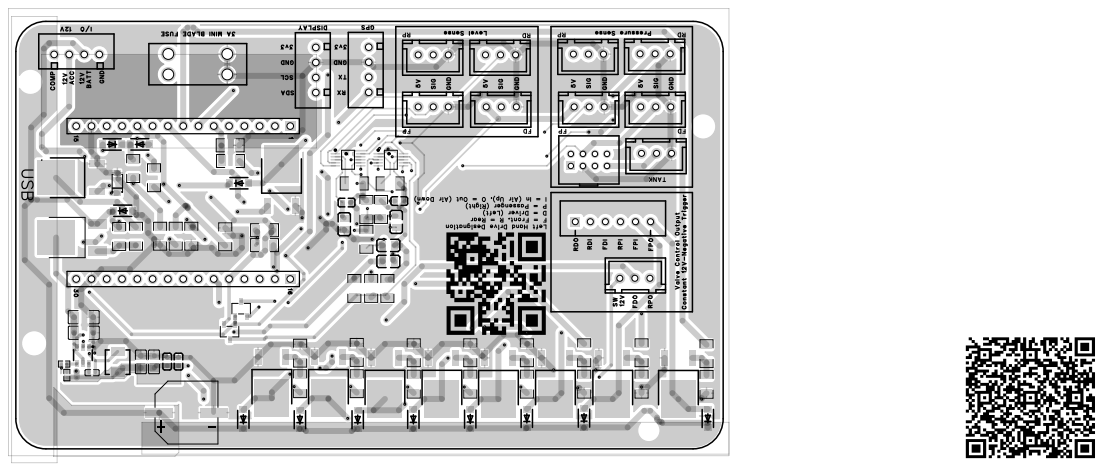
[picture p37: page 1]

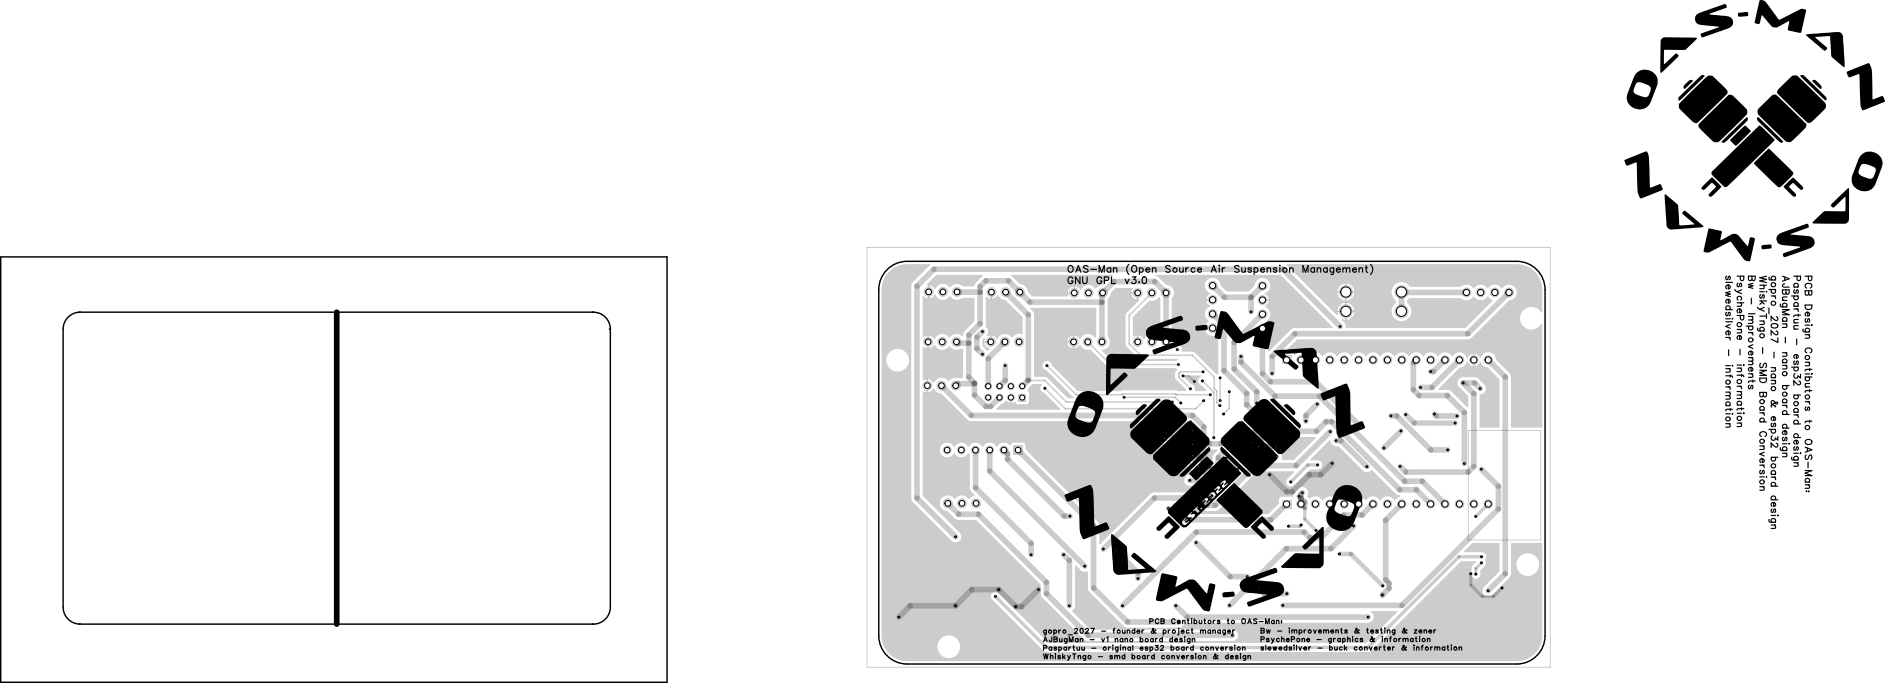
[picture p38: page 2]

OAS-Man (Open Source Air Suspension Management)
GNU GPL v3.0

WhiskyTngo - SMD Board Conversion

AJBugMan - nano board design

PCB Design Contibutors to OAS-Man:

gopro_2027 - founder & project manager
AJBugMan - v1 nano board design
Paspartuu - original esp32 board conversion
WhiskyTngo - smd board conversion & design

PCB Contibutors to OAS-Man:

Bw - improvements & testing & zener
PsychePone - graphics & information
slewedsilver - buck converter & information


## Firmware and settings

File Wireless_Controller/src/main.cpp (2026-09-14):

#include <Arduino.h>
#include <Preferences.h> // have to include it here or it isn't found in the shared libs

#if defined(OTA_SUPPORTED)
#include <directdownload.h>
#endif
#include <otarollback.h> // not behind OTA_SUPPORTED: any build may be running an unconfirmed image

#include <ui/ui.h>

#include "utils/touch_lib.h"
#include "utils/imu.h"
#include "utils/auto_rotate.h"
#include "utils/wake_on_movement.h"
#include "tasks/tasks.h"

#include "utils/util.h"

#ifndef SCREEN_MODE_CIRCLE
#include "custom_car_storage.h"
#endif

SET_LOOP_TASK_STACK_SIZE(12*1024); // the default 1024*8 how now reached it's limit with lvgl. Need to increase accordingly. lv_timer_handler() is the culprit.

unsigned long dimScreenTime = 0;
bool dimmed = false;

// set pin number for the boot button
// Not usable as a runtime input on every board: on ws4p3 GPIO0 is also an RGB data line, so
// USE_BOOT_BUTTON_FUNCTIONALITY is 0 there and every use below compiles out.
// See src/utils/util.h for the default.
const int BootButtonPin = 0;

void setup()
{

    Serial.begin(115200);
    
    // esp_bt_controller_mem_release(ESP_BT_MODE_BLE);
    esp_bt_controller_mem_release(ESP_BT_MODE_CLASSIC_BT); // should free a tad bit of memory
    // Serial.setDebugOutput(true);
    log_i("Board: %s", BOARD_NAME);
    log_i("CPU: %s rev%d, CPU Freq: %d Mhz, %d core(s)", ESP.getChipModel(), ESP.getChipRevision(), getCpuFrequencyMhz(), ESP.getChipCores());
    log_i("Free heap: %d bytes", ESP.getFreeHeap());
    log_i("Free PSRAM: %d bytes", ESP.getPsramSize());
    log_i("SDK version: %s", ESP.getSdkVersion());

    setupRestSemaphore();

    beginSaveData();

    // Check if in update mode and ignore everything else and just start the web server.
    if (getupdateMode())
    {
        setupdateMode(false);
        const bool allowInsecure = getotaInsecure();
        setotaInsecure(false); // applies to one update only
        Serial.println("Gonna try to download update");
    #if defined(OTA_SUPPORTED)
        downloadUpdate(getwifiSSID(), getwifiPassword(), allowInsecure);
    #else
        (void)allowInsecure;
    #endif
        return;
    }

    setup_tasks();

    board_drivers_init();

    // After board_drivers_init() because it owns I2C_Init(), and before ui_init() because the
    // settings screen asks imuAvailable() whether to show the auto rotate switch. The driver
    // itself is feature-agnostic; auto rotate is just its first consumer.
    imuInit();

#ifndef SCREEN_MODE_CIRCLE
    loadCustomImagesFromSpiffs();
#endif

#ifdef HAS_ROTARY_ENCODER
    knob_config_t knob_cfg = {
        .gpio_encoder_a = ENCODER_PIN_A,
        .gpio_encoder_b = ENCODER_PIN_B,
    };
    g_knob_handle = iot_knob_create(&knob_cfg);
    if (!g_knob_handle)
        log_e("Rotary encoder init failed");
#endif

    ui_init();

    setup_touchscreen_hook();

    dimScreenTime = millis() + getScreenDimTimeMs();

#if defined(OTA_SUPPORTED)
    checkUpdateRolledBack();
    byte updateResult = getupdateResult();
    if (updateResult != UPDATE_STATUS::UPDATE_STATUS_NONE)
    {
        switch (updateResult)
        {
        case UPDATE_STATUS::UPDATE_STATUS_FAIL_FILE_REQUEST:
            showDialog("Update failed (file request)", lv_color_hex(0xFF0000));
            currentScr->showMsgBox("Update failed", "There was an issue obtaining the firmware file", NULL, "OK", []() -> void {}, []() -> void {}, false);
            break;
        case UPDATE_STATUS::UPDATE_STATUS_FAIL_GENERIC:
            showDialog("Update failed (generic)", lv_color_hex(0xFF0000));
            currentScr->showMsgBox("Update failed", "Unknown error installing update", NULL, "OK", []() -> void {}, []() -> void {}, false);
            break;
        case UPDATE_STATUS::UPDATE_STATUS_FAIL_VERSION_REQUEST:
            showDialog("Update failed (version request)", lv_color_hex(0xFF0000));
            currentScr->showMsgBox("Update failed", "Could not retreive the version info", NULL, "OK", []() -> void {}, []() -> void {}, false);
            break;
        case UPDATE_STATUS::UPDATE_STATUS_FAIL_WIFI_CONNECTION:
            showDialog("Update failed (wifi connection)", lv_color_hex(0xFF0000));
            currentScr->showMsgBox("Update failed", "Could not connect to wifi network. Please check your wifi SSID and password", NULL, "OK", []() -> void {}, []() -> void {}, false);
            break;
        case UPDATE_STATUS::UPDATE_STATUS_FAIL_WIFI_PASSWORD:
            showDialog("Update failed (wifi password)", lv_color_hex(0xFF0000));
            currentScr->showMsgBox("Update failed", "The wifi network rejected the password. Please check your wifi password and try again", NULL, "OK", []() -> void {}, []() -> void {}, false);
            break;
        case UPDATE_STATUS::UPDATE_STATUS_FAIL_WIFI_NO_NETWORK:
            showDialog("Update failed (wifi not found)", lv_color_hex(0xFF0000));
            currentScr->showMsgBox("Update failed", "Could not find that wifi network. Please check your wifi SSID and that the network is in range", NULL, "OK", []() -> void {}, []() -> void {}, false);
            break;
        case UPDATE_STATUS::UPDATE_STATUS_FAIL_CORRUPT_DOWNLOAD:
            showDialog("Update failed (corrupt download)", lv_color_hex(0xFF0000));
            currentScr->showMsgBox("Update failed", "The downloaded firmware did not match its checksum, so it was not installed. Your device is untouched. Please try again", NULL, "OK", []() -> void {}, []() -> void {}, false);
            break;
        case UPDATE_STATUS::UPDATE_STATUS_FAIL_WEAK_CONNECTION:
            showDialog("Update failed (weak connection)", lv_color_hex(0xFF0000));
            currentScr->showMsgBox("Update failed", "The download timed out because of a weak or poor connection. Please move closer to your wifi and try again", NULL, "OK", []() -> void {}, []() -> void {}, false);
            break;
        case UPDATE_STATUS::UPDATE_STATUS_FAIL_ROLLED_BACK:
            showDialog("Update reverted", lv_color_hex(0xFF0000));
            currentScr->showMsgBox("Update reverted", "The new firmware did not start up correctly, so your device went back to the previous version", NULL, "OK", []() -> void {}, []() -> void {}, false);
            break;
        case UPDATE_STATUS::UPDATE_STATUS_FAIL_SECURE_CONNECTION:
            showDialog("Update failed (secure connection)", lv_color_hex(0xFF0000));
            currentScr->showMsgBox("Update failed", "Could not verify a secure connection to the update server. If this keeps happening, turn on Allow insecure update in the update settings and try again", NULL, "OK", []() -> void {}, []() -> void {}, false);
            break;
        case UPDATE_STATUS::UPDATE_STATUS_FAIL_ALREADY_UP_TO_DATE:
            showDialog("Update not needed", lv_color_hex(0xFFFF00));
            currentScr->showMsgBox("Update aborted", "You are already on the latest release", NULL, "OK", []() -> void {}, []() -> void {}, false);
            break;
        case UPDATE_STATUS::UPDATE_STATUS_SUCCESS:
        {
            showDialog("Update success!", lv_color_hex(0x00FF00));
            char buf[170];
            snprintf(buf, sizeof(buf), "Welcome to version %s!\nPlease check the manifold update status in the update section of settings to verify the manifold was updated successfully too.", EVALUATE_AND_STRINGIFY(RELEASE_VERSION));
            currentScr->showMsgBox("Update success!", buf, NULL, "OK", []() -> void {}, []() -> void {}, false);
            break;
        }
        default:
            // A status written by a newer firmware than this UI knows about.
            showDialog("Update failed (unknown)", lv_color_hex(0xFF0000));
            currentScr->showMsgBox("Update failed", "Unknown update status", NULL, "OK", []() -> void {}, []() -> void {}, false);
            break;
        }
        setupdateResult(0);
    }
#endif
    set_brightness(getBrightnessFloat());
#if USE_BOOT_BUTTON_FUNCTIONALITY
    pinMode(BootButtonPin, INPUT);
#endif
}

// auto lv_last_tick = millis();
static int lastFreeHeap = 0;
static unsigned long lastMemLog = 0;

// variables for storing the pushbutton status
int BootButtonState = 0;
unsigned long bootBtnLastPressed = 0;
unsigned long bootBtnLastReleased = 0;
unsigned long bootBtnHoldTime = 0;
bool bootButtonControllingAirUp = false;
bool bootButtonLoadPresetStarted = false;
int bootButtonPresetCount = 0;

bool isScreenDimmed()
{
    return dimmed;
}

void wakeScreenFromDim() {
    auto const now = millis();
    if (dimmed)
    {
        set_brightness(getBrightnessFloat());
        dimmed = false;
    }
    dimScreenTime = now + getScreenDimTimeMs();
}

int bootButtonCutoffTime = 500; // the cutoff time between a quick press and a long press
int beginAirUpAfterQuickPressActivationPeriod = 750; // the time after a quick press that we will watch for the second long press to begin the air up procedure
int beginPresetLoadingAfterNoInputPeriod = 1000; // the time after the last button press that we will start loading the preset procedure

void bootButtonFunctionality() {
#if !USE_BOOT_BUTTON_FUNCTIONALITY
    // No usable BOOT button on this board -- see the note by BootButtonPin above.
    return;
#else
    auto const now = millis();
    static bool lastBootButtonState = digitalRead(BootButtonPin);
    if (isDriveLockActive()) {
        bootButtonLoadPresetStarted = false;
        bootButtonControllingAirUp = false;
        closeValves();
        BootButtonState = 0;
        bootBtnLastReleased = now;
        if (digitalRead(BootButtonPin) != lastBootButtonState) {
            rejectIfDriveLocked(); // show dialog
            wakeScreenFromDim();
        }
        lastBootButtonState = digitalRead(BootButtonPin);
        return;
    }
    
    if (digitalRead(BootButtonPin) == LOW && BootButtonState == 0) {
        wakeScreenFromDim();
        BootButtonState = 1;
        Serial.println("Boot button pressed");
        // upon button press, check if the previous press was a quick press (<500ms) and that we aren't in the preset procedure
        // if so, start air up
        if (bootBtnHoldTime < bootButtonCutoffTime && !bootButtonLoadPresetStarted) {
            // if the current press is within 750ms of the last press, start the air up procesure
            if (now - bootBtnLastPressed < beginAirUpAfterQuickPressActivationPeriod) {
                bootButtonControllingAirUp = true;
                showDialog("Airing up while held", lv_color_hex(0x00FF00));
                // air up
                setValveBit(FRONT_DRIVER_IN);
                setValveBit(FRONT_PASSENGER_IN);
                setValveBit(REAR_DRIVER_IN);
                setValveBit(REAR_PASSENGER_IN);
            }
        }
        if (bootButtonLoadPresetStarted) {
            bootButtonPresetCount++;
            if (bootButtonPresetCount > getPresetCount()) {
                showDialog("Preset loading cancelled", lv_color_hex(0xFF0000));
                bootButtonLoadPresetStarted = false;
            } else {
                static char buf[14];
                snprintf(buf, sizeof(buf), "Preset %i...", bootButtonPresetCount);
                showDialog(buf, lv_color_hex(0xFFFF00));
            }
        }
        bootBtnLastPressed = now;
    } else if (digitalRead(BootButtonPin) == HIGH && BootButtonState == 1) {
        wakeScreenFromDim();
        BootButtonState = 0;
        Serial.println("Boot button released");
        bootBtnLastReleased = now;
        bootBtnHoldTime = bootBtnLastReleased - bootBtnLastPressed;
        // if long pressed and the long press wasn't for the emergency air up, start loading the preset procedure
        if (bootBtnHoldTime > bootButtonCutoffTime && !bootButtonLoadPresetStarted && !bootButtonControllingAirUp) {
            bootButtonLoadPresetStarted = true;
            bootButtonPresetCount = 0;
            showDialog("Select preset...", lv_color_hex(0xFFFF00), 30000);
        }
        // upon button release, stop air up if it was being controlled
        if (bootButtonControllingAirUp) {
            bootButtonControllingAirUp = false;
            showDialog("Airing up stopped", lv_color_hex(0xFFFF00));
            // stop air up
            unsetValveBit(FRONT_DRIVER_IN);
            unsetValveBit(FRONT_PASSENGER_IN);
            unsetValveBit(REAR_DRIVER_IN);
            unsetValveBit(REAR_PASSENGER_IN);
        }
    }

    // check if button is currently being held
    if (bootBtnLastPressed > bootBtnLastReleased) {
        // check if held longer than 500ms, and that we aren't in the preset procedure or air up procedure
        if (now - bootBtnLastPressed > bootButtonCutoffTime && !bootButtonLoadPresetStarted && !bootButtonControllingAirUp) {
            showDialog("Select preset...", lv_color_hex(0xFFFF00), 30000);
        }
    }

    // check if preset procedure is started
    if (bootButtonLoadPresetStarted) {
        // check if button is released for longer than 1000ms (stopped changing preset numbers)
        if (now - bootBtnLastReleased > beginPresetLoadingAfterNoInputPeriod) {
            bootButtonLoadPresetStarted = false;
            if (bootButtonPresetCount >= 1 && bootButtonPresetCount <= getPresetCount()) {
                // send the preset first to the manifold
                AirupQuickPacket pkt(bootButtonPresetCount - 1);
                sendRestPacket(&pkt);

                // update presets page if preset changes
                if (currentPreset != bootButtonPresetCount) {
#if defined(SCREEN_MODE_CIRCLE)
                    scrHome.setPreset(bootButtonPresetCount);
#else
                    scrPresets.setPreset(bootButtonPresetCount);
#endif
                }

                // show dialog of selected preset
                static char buf[20];
                snprintf(buf, sizeof(buf), "Preset %i loaded!", bootButtonPresetCount);
                showDialog(buf, lv_color_hex(0x00FF00));
            } else {
                showDialog("Preset loading cancelled", lv_color_hex(0xFF0000));
            }
        }
    }
    lastBootButtonState = digitalRead(BootButtonPin);
#endif // USE_BOOT_BUTTON_FUNCTIONALITY
}

void loop()
{
    auto const now = millis();

    otaVerifyLoop();

    bootButtonFunctionality();

    // Dev memory logging every 5 seconds
    if (now - lastMemLog >= 5000) {
        lastMemLog = now;
        int currentFreeHeap = ESP.getFreeHeap();
        int delta = (lastFreeHeap > 0) ? (currentFreeHeap - lastFreeHeap) : 0;
        lastFreeHeap = currentFreeHeap;

        // Stack monitoring - get high water mark (minimum free stack space ever seen)
        // Low values (< 512 bytes) indicate risk of stack overflow
        UBaseType_t stackHighWaterMark = uxTaskGetStackHighWaterMark(NULL);

        printf("[MEM] Heap Free: %d | Min: %lu | MaxAlloc: %lu | Delta: %d | Stack Free: %u bytes\n",
              currentFreeHeap, ESP.getMinFreeHeap(), ESP.getMaxAllocHeap(), delta, stackHighWaterMark);
    }

    if (isTouched())
    {
        wakeScreenFromDim();
    }

    if (dimScreenTime < now && dimmed == false)
    {
        set_brightness(0.01f);
        dimmed = true;
    }

    // screen code
    screenLoop();
    dialogLoop();
    safetyModeMsgBoxCheck();

    // Rebuilds the whole UI when it fires, so it has to run on this task (LVGL is
    // single-threaded here) and outside any LVGL event callback.
    autoRotateLoop();

    // After the dim check above, so it sees the dim edge in the iteration it happens.
    wakeOnMovementLoop();


    // Update the ticker
    // lv_tick_inc(now - lv_last_tick);
    // lv_last_tick = now;
    // Update the UI
    // Sleep only until LVGL next needs to run, clamped to [1,5]ms so the BLE/Waveshare/IDLE
    // tasks always get CPU time. The upper clamp also covers LV_NO_TIMER_READY (UINT32_MAX).
    uint32_t lv_idle_ms = lv_timer_handler(); // ; was: lv_timer_handler() + fixed vTaskDelay(5)
    if (lv_idle_ms > 5)
        lv_idle_ms = 5;
    else if (lv_idle_ms < 1)
        lv_idle_ms = 1;
    vTaskDelay(pdMS_TO_TICKS(lv_idle_ms));
}

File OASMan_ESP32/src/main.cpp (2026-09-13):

// OASMan ESP32

#include <Preferences.h> // have to include it here or it isn't found in the shared libs
#include <user_defines.h>
#include "input_type.h"
#include "components/wheel.h"
#include "components/compressor.h"
#include "components/AuxillaryOutput.h"
#include "bitmaps.h"
#include "manifoldSaveData.h"
#include "airSuspensionUtil.h"
#include "tasks/tasks.h"
#include <directdownload.h>
#include <otarollback.h>

#include <SPIFFS.h>

extern bool ADS1115D_exists;

// #define FORCE_UPDATE_TEST
void setup()
{
    Serial.begin(SERIAL_BAUD_RATE);
    Serial.println(F("Startup!"));

    SPIFFS.begin(true);

    beginSaveData();

    // Check if in update mode and ignore everything else and just start the web server.
    if (getupdateMode())
    {
        setupdateMode(false);
        const bool allowInsecure = getotaInsecure();
        setotaInsecure(false); // applies to one update only
        Serial.println("Gonna try to download update");
        downloadUpdate(getwifiSSID(), getwifiPassword(), allowInsecure);
        return;
    }

    checkUpdateRolledBack();

#ifdef FORCE_UPDATE_TEST
    for (int i = 0; i < 10; i++)
    {
        log_i("T-%d", 10 - i);
        delay(1000);
    }
    log_i("TEST updating");
    setupdateMode(true);
    delay(100);
    ESP.restart();
#endif

    // clearPressureData();

    // trainAIModels();

    delay(200); // wait for voltage stabilize

    setupADCReadMutex();
    setupWheelLockSem();

    setupManifold();

    delay(20);

    pressureInputs[0] = pressureSensorInput0;
    pressureInputs[1] = pressureSensorInput1;
    pressureInputs[2] = pressureSensorInput2;
    pressureInputs[3] = pressureSensorInput3;
    if (ADS1115D_exists) {
        pressureInputs[4] = pressureSensorInput4_adsd1115d;
    } else {
        pressureInputs[4] = pressureSensorInput4_directesp32;
    }

    wheel[WHEEL_FRONT_PASSENGER] = new Wheel(FRONT_PASSENGER_IN, FRONT_PASSENGER_OUT, pressureInputs[getpressureInputFrontPassenger()], levelInputFrontPassenger, WHEEL_FRONT_PASSENGER);
    wheel[WHEEL_REAR_PASSENGER] = new Wheel(REAR_PASSENGER_IN, REAR_PASSENGER_OUT, pressureInputs[getpressureInputRearPassenger()], levelInputRearPassenger, WHEEL_REAR_PASSENGER);
    wheel[WHEEL_FRONT_DRIVER] = new Wheel(FRONT_DRIVER_IN, FRONT_DRIVER_OUT, pressureInputs[getpressureInputFrontDriver()], levelInputFrontDriver, WHEEL_FRONT_DRIVER);
    wheel[WHEEL_REAR_DRIVER] = new Wheel(REAR_DRIVER_IN, REAR_DRIVER_OUT, pressureInputs[getpressureInputRearDriver()], levelInputRearDriver, WHEEL_REAR_DRIVER);

    compressor = new Compressor(compressorRelayPin, pressureInputs[getpressureInputTank()]);
    auxillaryOutput = new AuxillaryOutput(auxillaryOutputPin);
    rfReceiver = new RfReceiver();

    if (getlearnPressureSensors())
    {
        setlearnPressureSensors(false);
        PressureSensorCalibration::learnPressureSensorsRoutine();
    }

    accessoryWireSetup();
    ebrakeWireSetup();

    setup_tasks();

#if TEST_MODE == false
    // only want to rise on start if it was a full boot and not a quick reboot
    if (getinternalReboot() == false && getsafetyMode() == false)
    {
        if (getriseOnStart() == true)
        {
            // TODO: make base profile work (look in other spots in app for this)
            // readProfile(getbaseProfile());// TODO: add functionality for this in the controller
            loadProfileAirUp(RIDE_HEIGHT_PRESET_NUMBER);
        }
    }
#endif

    setinternalReboot(false);

    setupLEDs();

    Serial.println(F("Startup Complete"));
}

void loop()
{
    otaVerifyLoop();

    accessoryWireLoop();
    ebrakeWireLoop();
    if (getinternalReboot() == true)
    {
        ESP.restart();
    }

    delay(100);
}

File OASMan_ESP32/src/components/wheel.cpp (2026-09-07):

#include "wheel.h"
#include "manifold.h"

#define NUM_WHEEL_THREADS 4
std::atomic<bool> flagStartPressureGoalRoutine[NUM_WHEEL_THREADS];

extern bool isVehicleParked(bool dontTrustEBrakeAlone = false, bool requireBothAccAndEbrake_or_GPS = false); // defined in airSuspensionUtil.cpp
extern bool isAnyWheelActive();            // defined in airSuspensionUtil.cpp

int getMinValveOpenPSI()
{
    return 0;
}

Wheel::Wheel() {}

Wheel::Wheel(int solenoidInPin, int solenoidOutPin, InputType *pressurePin, InputType *levelSensorPin, byte thisWheelNum)
{
    this->pressurePin = pressurePin;
    this->levelSensorPin = levelSensorPin;
    this->thisWheelNum = thisWheelNum;
    this->s_AirIn = solenoidInPin;
    this->s_AirOut = solenoidOutPin;
    this->pressureValue = 0;
    this->pressureGoal = 0;
    this->routineStartTime = 0;
    // this->flagStartPressureGoalRoutine = false;
    flagStartPressureGoalRoutine[thisWheelNum] = false;
}

Solenoid *Wheel::getInSolenoid()
{
    return getManifold()->get(this->s_AirIn);
}

Solenoid *Wheel::getOutSolenoid()
{
    return getManifold()->get(this->s_AirOut);
}

InputType *Wheel::getPressurePin()
{
    return this->pressurePin;
}

float analogToRange(int nativeAnalogValue)
{
    float floored = float(nativeAnalogValue) - pressureZeroAnalogValue;  // chop off the 0 value
    float totalRange = pressureMaxAnalogValue - pressureZeroAnalogValue; // get the total analog voltage difference between min and max
    float normalized = floored / totalRange;                             // 0 to 1 where 0 is 0psi and 1 is max psi
    return normalized;
}

float analogToPressure(int nativeAnalogValue)
{
    return analogToRange(nativeAnalogValue) * getpressureSensorMax(); // multiply out 0 to 1 by our max psi
}

float analogToHeightPercentage(int nativeAnalogValue)
{
    return analogToRange(nativeAnalogValue) * getHeightSensorMax(); // multiply out 0 to 1 by 100 to get a percentage
}

// Testing function, convert pressure value back to analog value, exact reverse of analogToPressure
float pressureToAnalog(float psi)
{
    float totalRange = pressureMaxAnalogValue - pressureZeroAnalogValue; // get the total analog voltage difference between min and max
    return (psi / getpressureSensorMax()) * totalRange + pressureZeroAnalogValue;
}

float readPinPressure(InputType *pin, bool heightMode)
{
    if (heightMode == false)
    {
        return analogToPressure(pin->analogRead());
    }
    else
    {
        return analogToHeightPercentage(pin->analogRead());
    }
}

// Raw (pre-normalization, pre-invert) height sensor reading, used to capture calibration points
float Wheel::readLevelSensorRaw()
{
    return readPinPressure(this->levelSensorPin, true);
}

// Normalize a raw 0-100 height reading into 0-100 between the per-wheel calibrated
// min/max points. Defaults (min=0, max=100) make this an identity mapping.
float Wheel::readLevelSensorNormalized()
{
    float calMin = getheightCalMin(this->thisWheelNum);
    float calMax = getheightCalMax(this->thisWheelNum);

    float reading = this->readLevelSensorRaw(); // always 0 to 100

    bool inverted = calMin > calMax;

    if (inverted) {
        float tmp = calMin;
        calMin = calMax;
        calMax = tmp;
    }

    float range = calMax - calMin;
    
    if (fabsf(range) < 0.001f)
    {
        return reading; // degenerate calibration, skip normalization
    }
    float normalized = ((reading - calMin) / range) * getHeightSensorMax();
    if (normalized < 0.0f)
    {
        normalized = 0.0f;
    }
    if (normalized > getHeightSensorMax())
    {
        normalized = getHeightSensorMax();
    }
    if (inverted) {
        normalized = getHeightSensorMax() - normalized;
    }
    return normalized;
}

void Wheel::readInputs()
{
    this->pressureValue = readPinPressure(this->pressurePin, false);
    if (getheightSensorMode())
    {
        this->levelValue = readLevelSensorNormalized();
    }
}

float Wheel::getSelectedInputValue()
{
    float value = getheightSensorMode() ? this->levelValue : this->pressureValue;
    if (value < 0)
    {
        return 0;
    }
    else
    {
        return value;
    }
}

bool Wheel::isActive()
{
    return getInSolenoid()->isOpen() || getOutSolenoid()->isOpen() || flagStartPressureGoalRoutine[thisWheelNum].load();
}

bool Wheel::initPressureGoal(int newPressure, bool onlyAirUp, std::function<void()> onComplete)
{

    if (newPressure > (getheightSensorMode() ? getHeightSensorMax() * 1.03f : getbagMaxPressure()))
    {
        // hardcode not to go above set psi
        return false;
    }
    int pressureDif = newPressure - this->getSelectedInputValue(); // negative if airing out, positive if airing up
    if (abs(pressureDif) > getMinValveOpenPSI())
    {
        // okay we need to set the values, but only if we are airing out or if the tank has more pressure than what is currently in the bags
        bool tankIsLowerThanBag = false;
        if (getheightSensorMode() == false)
        {
            // it's in pressure mode, check if tank is less than whats currently in the bag and if it is then tankIsLowerThanBag is true.
            // we don't care about the goal because we still want to try to reach the goal even if the tank isn't capable. We do care if tank is more than the bag though because if it's less than the bag then it will actually air out.
            if (getCompressor()->getTankPressure() < this->getSelectedInputValue())
            {
                tankIsLowerThanBag = true;
            }
        }
        if (pressureDif < 0 || !tankIsLowerThanBag)
        {
            this->pressureGoal = newPressure;
            this->routineStartTime = millis();
            this->onlyAirUp = onlyAirUp;
            this->onPressureGoalComplete = onComplete;
            flagStartPressureGoalRoutine[thisWheelNum] = true;
            return true;
        }
    }
    return false;
}

bool Wheel::initPressureGoal(int newPressure, std::function<void()> onComplete)
{
    return this->initPressureGoal(newPressure, false, onComplete);
}

// height sensor: AA-ROT-120 https://www.aliexpress.us/item/3256807527882480.html https://www.amazon.com/Height-Sensor-Suspension-Leveling-AA-ROT-120/dp/B08DJ3HX1B https://www.aliexpress.us/item/3256806751644782.html
// Output voltage UA:0.5-4.5

int wheelLoopBittset = 0;

static SemaphoreHandle_t wheelLockSem;
void setupWheelLockSem()
{
    wheelLockSem = xSemaphoreCreateMutex();
}

void wheelThreadLock()
{
    while (xSemaphoreTake(wheelLockSem, 1) != pdTRUE)
    {
        delay(1);
    }
}

void wheelThreadUnlock()
{
    xSemaphoreGive(wheelLockSem);
}

static int goalSyncClubSize = 0;
static int goalSyncWaiting = 0;
static int goalSyncGeneration = 0;
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

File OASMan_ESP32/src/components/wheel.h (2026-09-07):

#ifndef wheel_h
#define wheel_h

#include <Arduino.h>
#include <Wire.h>
#include <SPI.h>
#include <atomic>
#include <functional>
#include <user_defines.h>
#include "input_type.h"
#include "solenoid.h"
#include "compressor.h"
#include "manifoldSaveData.h"
#include "../aiPressureUtil.h" // getPredictedBagPressure / recordLearnSample

class Manifold; // from manifold.h, forward reference

class Wheel
{
private:
    InputType *pressurePin;
    InputType *levelSensorPin;
    byte thisWheelNum;

    byte pressureGoal;
    unsigned long routineStartTime;

    float pressureValue;
    float levelValue;

    int s_AirIn;
    int s_AirOut;

    // Sensorless levelling per-corner runtime state (see Wheel::heightsensorlessLevelling())
    float slLastSample = 0;             // pressure-stability window reference reading
    unsigned long slParkedSince = 0;    // when continuous parked state began (0 = not parked)
    unsigned long slLastInstabilityDetectedTimeMS = 0;    // when current pressure-stable window began (0 = none)
    unsigned long slLastCorrection = 0; // last correction time (for cooldown)
    int8_t slSameDirCount = 0;          // signed run-length of same-direction corrections
    // Baseline capture (see Wheel::sensorlessCaptureBaseline())
    unsigned long slValvesClosedSince = 0; // when all valves last became closed (0 = a valve is open)
    bool slBaselineCaptured = false;       // captured the baseline once for the current valve-close event
    byte directlySetPressure = 0; // This is the 'real' pressure that is read after any valve movement. This is our 'expected' pressure in a sense. This is tracked by the sensorlessCaptureBaseline and is only usable when slBaselineCaptured is true.

    void goalRoutine();
    // Fine precision phase: short valve bursts to the exact pressure. True = landed on goal.
    bool achieveFineGoal();
    // Block until the reading holds within `band` for SETTLE_STABLE_MS, then return it (valves closed).
    double waitForStableReading(int band);
    // Open `valve` for `ms`, then close it. Used by the fine phase.
    void openValveForMs(Solenoid *valve, uint32_t ms);
    // Log an offset sample from a manual valve move (watched by valve state each Wheel::loop tick).
    void captureManualOffsetSample();
    bool manualValveWasOpen = false;
    bool manualUp = false;                // direction of the tracked manual move (picks the settle time)
    uint32_t manualSettleUntil = 0;       // while non-zero: valve closed, waiting to read the settled bag
    uint8_t manualFlowBag = 0, manualFlowTank = 0;
    SOLENOID_AI_INDEX manualAiIndex = AI_MODEL_UNDEFINED;
    void maintainPressure();
    void heightsensorlessLevelling();
    void pressureCaptureBaseline();
    void nullifySensorlessBaseline();
    void markInstability(float current);

    bool onlyAirUp = false;
    std::function<void()> onPressureGoalComplete;
    void trackPressureStability();
    bool isPressureStable();

    float readLevelSensorNormalized();
    bool haveValvesBeenClosedForSomeTime(uint32_t additionalTimeMS = 0);

public:
    Wheel();
    Wheel(int solenoidInPin, int solenoidOutPin, InputType *pressurePin, InputType *levelSensorPin, byte thisWheelNum);
    bool initPressureGoal(int newPressure, std::function<void()> onComplete = nullptr);
    bool initPressureGoal(int newPressure, bool onlyAirUp, std::function<void()> onComplete = nullptr);
    void loop();
    void readInputs();
    float readLevelSensorRaw();
    float getSelectedInputValue();
    bool isActive();
    Solenoid *getInSolenoid();
    Solenoid *getOutSolenoid();
    InputType *getPressurePin();
};

float readPinPressure(InputType *pin, bool heightMode);

void setupWheelLockSem();

extern Manifold *getManifold(); // defined in airSuspensionUtil.h
extern bool isVehicleOn();      // defined in airSuspensionUtil.h
#endif

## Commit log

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2023-01-22 added pics and test for a bug in arduino
    [Manifold Base.stl, manifoldmount.FCStd, mannifoldmount.stl]
2023-01-23 Fixes
    Added code to close the solenoid during airup to get a properly read pressure value to check against. It's not perfect yet, need to figure out how to get a more accurate reading on the airup. I think doing multiple at a time with delay causes the wack issue.
    [Tylers PCB.kicad_pcb, Tylers PCB.kicad_sch, bom.csv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]
2023-01-24 Made airing up reliable to correct PSI
    [wheel.cpp, wheel.h]
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2023-01-29 Changes
    Implemented raise on pressure set
    Toggled time values for open and close
    Made airout pause for the airup timing because air out happens much quicker and more accurately than air up and it was causing bad values before by like 30psi too low
    [wheel.cpp, wheel.h]
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2023-03-09 Many changes
    Added average values,
    Added new command to raise all by a set psi
    Removed display code code
    Optimized wheel class to use less ram
    Fixed a bug with the profiles
    Added code to send profile data back to app when loading a profile
    [wheel.cpp, wheel.h]
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2023-03-09 fixed small thing in app and added some code for percision in arduino
    [wheel.cpp, wheel.h]
2023-05-04 Joying dev fixes!
    Things may be broken... idc
    also made a small change to times in wheel.cpp, and commented out AT setup in airsuspension_controller.ino
    [app_widget_background.xml, app_widget_inner_view_background.xml]
2023-05-05 hmm more code
    drivers side rear is having issues... seems like output valve is stuck open. need to analyze
    [wheel.cpp, wheel.h]
2023-08-05 Added skip percise on +10-10 and quick air up
    [wheel.cpp, wheel.h]
2023-11-22 Bug fixes, quality of life
    Min SDK Version changed by 1 version older (so I can test on the note 8)
    Viewing portion of the page changed to be exact size of screen to fill the area, and adjusted the position of the pressures.
    Changed the names of the quick select icons to a more functional name, even though they are hardcoded and it's not super ideal... we are running on low arduino space!
    Fixed the bug where the pressure scroll wheels would be blank sometimes.
    Fixed the part of the code that makes it retry connections so it will properly retry. Seems to function well now?
    Tried to add code to early-end the connection to make it retry quicker but it didn't work, caused issues of course.
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2023-12-18 Added a redundancy check in the solenoid code
    Wanted to add redundancy so I can call it multiple times without actually calling the digitalWrite function if it doesn't need to be called... I think this should be fine.
    Worth mentioning that I added this while thinking of how the compressor code is written, check the part where it closes in the compressor code to see how they are related. It will continuously call Solenoid::close() when the max pressure is reached.
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2024-06-06 Added maintain pressure function & changed snackbar to toast & made success/error BT responses
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2024-10-16 Fixed naming error on arduino import
    [wheel.h]
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2024-11-14 Commented out the aliexpress mosfets because psychepone said they didn't work for him
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2024-11-14 Fixed go to pressure percise issue that was commented out
    [main.cpp, wheel.cpp, wheel.h]
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2024-11-21 Formatted every file & increased compressor stack size by 512 due to crash
    [main.cpp, tasks.cpp, wheel.cpp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]
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2024-12-02 New manifold base design
    Updated to be correct thickness but more importantly perfectly fit the nuts that come with the $100 ebay manifold
    [Manifold Base.stl]
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2024-12-06 Fixed issue with ads threading
    [tasks.cpp, wheel.cpp]
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2024-12-06 Fixed bug with valves being open causing issues reading voltages.
    [wheel.cpp]
2024-12-06 Made bt and ps3 work in harmony
    ps3 controller must be connected first for some reason tho. Trying to fix that in next commit maybe
    [tasks.cpp]
2024-12-06 Simplified bluetooth code
    Some of this code doesn't appear to be necessary anymore. Maybe it was for getting rid of bugs on the arduino nano? im not too sure. Seems to work fine with these updates.
    Also added a buffer length check and a delay in case it gets stuck waiting forever for a new line, we don't want it in an infinite loop without a delay.
2024-12-08 getMinValveOpenPSI returnd time (typically 20) instead of PSI, causing bug airing up
    Also added more to the valve timing algorithm to try
    [wheel.cpp]
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2024-12-11 replaced eeprom code with preferences code
    [main.cpp]
2024-12-13 fixed code to reboot properly
    [main.cpp]
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2025-01-24 Fixed ble but screen is slow
    Changed board in platformio to upesy_wroon and copied build flags over from esp32-2432S032C.json
    See: https://github.com/rzeldent/esp32-smartdisplay/issues/230
    [ble.cpp]
2025-01-24 Converted to NimBLE
    Fixed ble compattability with lvgl
    [ble.cpp]
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2025-02-04 idk why i added this in the first place. it was just causing issues
    [ble.cpp]
2025-02-05 fixed bugs, renamed 2.4 cuz bad
    [PCB_Esp32-Wroom-Air-suspension_2025-01-26.dxf]
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2025-02-07 disabled burn in fix code
    [main.cpp]
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2025-02-11 fixed preferences issue working on radioOption
    [main.cpp]
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2025-02-13 fixed rise on start
    [main.cpp]
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2025-02-23 Create touch remote fixed bottom battery sleeve.stl
    [touch remote fixed bottom battery sleeve.stl]
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2025-03-06 Added compressor override
    also:
    removed fall on shutdown in controller settings
    fixed bug with compressor frozen not showing correct value on controller
    made it show dev in controller settings when it's a non release build
    [ble.cpp]
2025-03-06 Added rise on start but gps moving always set to true so it doesn't work
    Decluttered the ACCESSORY_WIRE_FUNCTIONALITY define bc it was stupid
    Added AIR_OUT_AFTER_SHUTDOWN_MS default set to 5 seconds after car shutoff
    Added airOutWithSafetyCheck which is called after car is turned off but only if isCarMoving is false and it is currently always set to true until we add gps
    [ble.cpp]
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2025-03-31 Added safety mode (fixed commit)
    Blocks compressor and rise on start when enabled (enabled by default)
    Fixed ps3 to use correct reboot
    [main.cpp]
2025-04-03 possible hotfix for compressor issue
    [tasks.cpp]
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2025-04-14 stable point of this code. some issues with connections
    [ble.cpp]
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2025-04-25 Updated some basics on the flutter app
    Added primitive version of auth so it can authenticate with the default passcode for now
    Added valves and fixed the valve characteristic from PROPERTY_WRITE_NR to PROPERTY_WRITE since flutter didn't like the noResponse version
    [ble.cpp]
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2025-05-05 Gradient descent type not working great check chatgpt for suggestions to improve
    [wheel.cpp]
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2025-05-16 fixed test data and tested it a bit to make sure it didn't crash
    [main.cpp]
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2025-06-19 Fixed ocellations from being too op and undershooting sometimes. Now only starts when it has passed over a goal
    [wheel.cpp]
2025-06-19 Fixed part of the maintain pressure code so it won't try to maintain 0psi
    [wheel.cpp]
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2025-06-24 Replaced up down arrows with shitty little circle button things... should be improved in the future
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2025-07-10 Fixed a few syntax errors from claude but not perfect yet
    [ble.cpp]
2025-07-26 HOTFIX fixing wireless controller build lvgl version
    lvgl 9.3.0 breaks, force 9.2.2 until we fix the config for 9.3.0
2025-07-27 Fixed PIO config bugs
    for controller: forcing lvgl 9.2.2, and added commented out fix for 9.3.0 but currently not using due to memory constraints
    for manifold: set package directory as local to project to fix issue with bluepad32 framework getting overwritten when the controller project is opened
2025-07-31 Improve BLE connection handling
    Fixed connection speed by modifying the advertising data
    [ble.cpp]
2025-07-31 attempt to specify mtu but doesn't seem to work. oh well
    mtu appears to negotiate to max anyways. moved the print statement of the mtu output on client further down so it gets printed after negotiation. it seems negotiation always goes to max 517 even without l2cap_set_max_le_mtu
    [ble.cpp]
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2025-08-09 Unfinished added support for waveshare esp32 2.8
    includes basic json, it does boot on screen but no touch support yet and colors are wrong.
    can easily revert to the old CYD by commenting out and uncommenting the old in the platformio.ini file
    [s3_no_spiffs.csv]
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2025-08-14 Added battery and power key for waveshare board
    Battery not added to ui yet.
    Short button press = sleep
    Long button press = shutdown
    [PWR_Key.cpp, PWR_Key.h, main.cpp]
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2025-08-14 Fixed bug with NimBLE running out of memory
    On the waveshare device, have to specify NimBLE to use external memory.
    Also cloned the bluepad32 framework to my account and im using that on the board now
2025-08-27 Fixed code to not disconnect registered controllers from auth
    [ble.cpp]
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2025-08-31 Fixed the att_server_notify
    Not sure why, but it wanted a return statement even though it was unused! how odd
    [ble.cpp]
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2025-09-15 correcting some merge issues, some typos and mistakes. Added message type enums to the android app.
    [ble.cpp]
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2025-09-16 bug updates of the settings page. units and compressor pressure are still buggy
    [ble.cpp]
2025-09-17 it autoconnects, however the UI won't recognize/update
    [ble.cpp]
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2025-10-15 Some screen fixes
    Moved button code to separate task
    Added battery percentage to settings page
    [main.cpp, tasks.cpp]
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2025-11-25 Revert "added door lock drop functionality"
    This reverts commit 0080884372b553bab25666bf195ca6348a155753.
    [main.cpp]
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2025-11-26 Fixed boot backlight issue with random pixels
    Decided to render the logo as a splashscreen
    [Display_ST7789.cpp, board_driver_util.cpp, main.cpp]
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2025-11-30 Fixed rendering issues on 2p8b
    Changed screen frequency from 30Mhz to 16Mhz
    [main.cpp]
2025-12-01 Changed it from src to files because src caused weird issues
    I really don't understand why but it appears that using the src folder confused it and wouldn't allow it to properly load some things like the images folder
    [device_lib_exports.h]
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2025-12-08 Comment for githubreleasebinary-http-proxy updates
    The code on cloudflare was changed to force the url to start with the full https://github.com/gopro2027/ArduinoAirSuspensionController/releases/download/ in order for it to be allowed, to prevent other repos from abusing our reverse proxy
2025-12-08 Added rate limit check on the json info
    it will probably never be rate limited, but in the case that is does get rate limited, it will revert back to directly contact github.
    This code may honestly be removed in the future, not sure yet
    Also added the js files from the github proxy
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2025-12-08 Added new files to flashing page UI
    Also fixed issue with it not selecting boards that only have an older version
2025-12-08 Fixed lowercase k issue
    [device_lib_exports.h]
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2025-12-11 Fixed car coordinates on other devices by adding the SCALE_X and SCALE_Y to the values
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2025-12-17 Fixed backligh bug
    3.5 drivers were fighting mainline backlight control.
    Also reduced gfx begin from 100mhz to 80mhz for better stability.
    [LVGL_Driver.cpp]
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2026-01-17 Replaced wheel code direct usage of solenoids with manifold request
    Also added the chamber valve class but not like fully implemented into solenoid yet
    [main.cpp, wheel.cpp, wheel.h]
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2026-01-22 Fixed resolution on larger displays
    [board_driver_util.cpp]
2026-01-23 Fixed ui stuff for larger displays
    Removed manual coordinates
    Made pill buttons on home screen proper
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2026-01-23 Removed scrhome ui which was unused
    Also fixed slight issues with the rotation
    [board_driver_util.cpp, main.cpp]
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2026-01-24 update for presets/on-off switch
    removed switch images and replaced them with single ui_switch member.
    added offset for the car in landscape mode
    [main.cpp]
2026-01-25 fixed pressure unit bug
    fixed a bug with pressure units. If you changed e.g. PSI -> BAR it did not change it visually on the home/presets pages.
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2026-01-25 Fixed splash screens
    Also renamed settings page for the controller to screen
    [board_driver_util.cpp]
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2026-03-01 First pass of code, need to test and clean up bugs
    [ble.cpp, wheel.cpp]
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2026-03-02 Moved height sensor invert to read function
    [wheel.cpp]
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2026-03-02 Updated gfx library version to 1.6.5 in hopes it fixed the incompatability with latest version of arduino-esp32
    I'm not entirely sure why it's downloading a new version of arduino esp32 and not using a fixed verssion, but not looking into that right now. Here is a github issue of the error for reference: https://github.com/espressif/Arduino-esp32/issues/12328
2026-03-02 Fix for new core version in nimble
    [tasks.cpp]
2026-03-06 Fix for six valve manifold to force the compressor (and tank valve) off when tank output is opened
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2026-04-03 Fixed button press bug on air out, inverted arc so they all fill upwards
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2026-04-07 Performance boost
    fix: cache statusbar and pressure label values to prevent per-frame LVGL invalidation
    Statusbar::update() was called every frame and unconditionally setting
    text/color on battery, alert, and status widgets via lv_label_set_text()
    and lv_obj_set_style_text_color(). Each call triggers lv_obj_invalidate(),
    forcing LVGL to re-render those regions every frame even when nothing changed.
    Added cached values (battery string, icon, color, status bitmask) and
    skip updates when values are unchanged.
    Also fixed pressure labels in Scr.cpp: color was being set to white every
    frame via lv_obj_get_style_text_color() + comparison. Now only sets white
    once when the color isn't already whi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
2026-04-10 Fixed app name and icon
    [main.cpp]
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2026-05-17 4.0 Board update
    4.0 PCB complete update. Corrected zener and silk screen error.
    [BOM_OASman V4.0_PCB1_5_2025-09-03.csv, BOM_OASman V4.0_PCB1_5_2025-09-03.xlsx, BOM_OASman V4.0_PCB1_5_2026-05-16.csv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]
2026-05-18 4.0.1 HotFix
    4.0 Board corrections updated to 4.0.1 HotFix
    [BOM_OASman V4.0_PCB1_5_2025-09-03.csv, BOM_OASman V4.0_PCB1_5_2025-09-03.xlsx, BOM_OASman V4.0_PCB1_5_2026-05-16.csv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]
2026-05-18 Config packet issue fix
    Sometimes when saving a preset the config packet saves bad data from the stack to the board. This ensures that does not happen.
    [ble.cpp]
2026-05-19 Moved this code into the isAuthed
    It doesn't technically cause an issue, but that code would get ran by an unauthorized device. All it would do is simply copy possible stack values to the valveControlBittsetArr... maybe. Either way, they would be unused. But I think it sounds best to move it into the isAuthed block.
    [ble.cpp]
2026-06-11 Tap on dim screen will no longer execute item on screen
    Also set minimum screen timeout to 5s
    [main.cpp]
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2026-06-11 ws2p8: partial rendering with correctly sized internal-RAM buffers
    The old config rendered the FULL 153.6KB frame into PSRAM and pushed
    all of it through blocking, CPU-driven Arduino SPI on every refresh
    (>15ms wire time at 80MHz), even for a 1px change.
    It also mixed units: heap_caps_malloc() got LVGL_BUF_LEN bytes while
    lv_display_set_buffers() was told LVGL_BUF_LEN * sizeof(lv_color_t)
    (3 bytes in LVGL 9), declaring 3x more buffer than allocated. That
    overrun is why earlier partial-buffer attempts crashed; FULL mode only
    survived because LVGL caps usage at the real frame size there.
    Now: two 40-line (19.2KB) buffers sized in bytes, allocated from
    internal DMA-capable RAM (PSRAM/malloc f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
    [LVGL_Driver.cpp]
2026-06-11 ws3p5: drop identity color LUT, fix buffer math so internal DMA works
    The flush-path color correction ran an expand/LUT/repack transform on
    every flushed pixel with brightness=1.0, gamma=1.0 and all channel
    gains=1.0 - a mathematical no-op costing CPU on every flush. Disabled
    (code kept for future real calibration values).
    Buffer sizing used LVGL_BUFFER_LINES=480 (full height) multiplied by
    sizeof(lv_color_t), which is 3 bytes in LVGL 9: 460.8KB per buffer.
    The internal-DMA-preferred allocation could never succeed and both
    buffers silently fell back to slower PSRAM, 1.5x oversized. Now 60
    lines x 2 bytes = 38.4KB per buffer, so the internal-DMA path actually
    allocates, and ~900KB of PSRAM i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
2026-06-11 ws2p8b: honest buffer units and 60 FPS refresh target
    Buffer math relied on sizeof(lv_color_t) being the pixel size, but in
    LVGL 9 that type is 3 bytes regardless of LV_COLOR_DEPTH=16. The 20-line
    pixel count times 3 happened to equal 30 usable RGB565 rows; same
    28.8KB allocation now expressed directly as 30 lines x 2 bytes.
    Refresh timer overridden 33ms -> 16ms (same pattern ws1p8knob ships):
    the ST7701 RGB panel refreshes itself from its own frame buffers and
    LVGL only blits dirty strips, so 60 FPS is sustainable.
    Needs bench check on ws2p8b hardware: smooth scrolling, no drift or
    flicker artifacts, heap headroom unchanged in the [MEM] log.
    Verified: pio run -e controller_ws2p8b_dev (SU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
    [LVGL_Driver.cpp]
2026-06-11 ws3p5b: document frame-skip override and its bench-test requirements
    ENABLE_FRAME_SKIP stays default-off (no ws3p5b bench hardware available
    to verify). The comment now explains why it matters on this panel (FULL
    render mode pushes the whole 307KB frame over 60MHz QSPI, ~41ms/flush,
    ~20 FPS ceiling, even when idle), how to enable it per-build, and what
    to bench-check before shipping it enabled.
    Verified: pio run -e controller_ws3p5b_dev (SUCCESS, comment-only)
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2026-06-19 testing spiffs issue fix
    [custom_car_storage.cpp]
2026-06-21 Fixed partition text for 2.8
    [board_driver_util.cpp]
2026-06-21 Revert "Merge branch 'dev' of https://github.com/gopro2027/ArduinoAirSuspensionController into dev"
    This reverts commit 3c89725842e01fcda01f43f3b695e9d12fff62eb, reversing
    changes made to 94df349857041123678a0065d8371f2ecc592e42.
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2026-06-29 Removed lookup table and replaced with simple y=10x equation which almost perfectly matches the lookup table
    [wheel.cpp]
2026-06-30 Hopefully fixed the logic a bit for the height sensorless levelling
    Fixed bug with stableSince only setting once, and not always resetting every time it drifts
    Check if baseline is captured to actually execute the levelling (was missing before!)
    added nullifySensorlessBaseline to goalRoutine to make sure it gets reset on a goal 100% for sure
    made isActive check if inside a goalRoutine
    [wheel.cpp, wheel.h]
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2026-07-01 added error shutdown on both features
    also cleaned up code and where we call the mark instability and nullifySensorlessBaseline is perfected
    [wheel.cpp, wheel.h]
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2026-07-01 Added auto detect inverted height sensors
    [wheel.cpp]
2026-07-02 added stability check for maintain when in height level mode
    [wheel.cpp]
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2026-07-23 Fixed board boot timing issue
    [board_driver_util.cpp]
2026-07-24 Fixed scale on all the controllers by implementing a DPI value
    [device_lib_exports.h]
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2026-07-25 fixed height sensor calibration when inverted
    [wheel.cpp]
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2026-07-30 fixed stack size for training
    [tasks.cpp]
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2026-08-03 Global sync fix (untested)
    This should fix the issue with pressures getting stuck sometimes
    [wheel.cpp]
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2026-08-03 Update barrier wait timing fix
    [wheel.cpp]
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2026-08-04 Merged level sensor into pressure sensor code
    Benefits:
    Settle + verify now happens — height moves close → settle → re-read true height → correct, instead of the old tick-level bang-bang. More accurate (lets the suspension mechanically settle before judging), but slower: each correction adds a settle wait, and it reuses the pressure constants (250 ms up / 500 ms down). If height ends up hunting or feeling sluggish, those constants (or a small height deadband) are the knobs.
    Direction is now committed — it no longer recomputes up/down every tick and free-reverses; it commits and only reverses after a settle. That removes the old chatter.
    The 6-valve canOpen check now applies to heig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
    [wheel.cpp, wheel.h]
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2026-08-04 More linting
    Removed vestigal ai enabled config
    moved data files to samples folder
    Still need to test and make sure I didn't make the task_trainAI stack size too small
    [ble.cpp, main.cpp, tasks.cpp]
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2026-08-09 Some clean up
    clearPressureData safety mutex fix
    setupSpiffs unused
    getLogFileName default return
    local symbols set to static
    [main.cpp, tasks.cpp]
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2026-08-09 Fixed 3.5/b power button
    removed light sleep for 3.5 and also added DEVICE_HAS_HARD_SHUTDOWN for devices that support it on full shutdown.
    [PWR_Key.cpp, PWR_Key.h, device_lib_exports.h]
2026-08-11 Updated ota worker to allow empty tag
    also fixed blank tab when building manifold code locally in production mode (eg testing in board is built in production mode but tag was set to blank, so now it checks if tag is blank OR undefined and sets it to build-dev
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2026-08-15 Added very rudimentary version of learning to level sensor mode
    essentially just updated it so level sensor can also use the learning. Pitfalls at current state of implementation:
    1. user has to clear the learned data manually. height and pressure share the same file
    2. maybe the training isn't perfect for level sensor yet since it doesn't have all the same complications pressure does
    [wheel.cpp, wheel.h]
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2026-08-30 Fix usage of MAX_PRESSURE_SAFETY to getbagMaxPressure()
    The previous ai code here wrote a min between MAX_PRESSURE_SAFETY in from user defines and getbagMaxPressure(), however getbagMaxPressure literally is MAX_PRESSURE_SAFETY
    [wheel.cpp]
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2026-09-06 note about the reset issue with 4p3
    [device_lib_exports.h]
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2026-09-07 Explained in the comment. noinline the getBLEConnectedClientCount
    Prevents the compiler from setting the value to const 0 instead of reading .size() in other threads.
    [ble.cpp]
2026-09-07 Fix BLE notify task deadlock after unclean client disconnect
    The in-car controller randomly refused to connect to the manifold after the
    web controller (oasman.co/controller) dropped without a clean UI disconnect.
    packetMover queue entries are keyed by hci_con_handle_t and are independent
    of authedClients. On DISCONNECTION_COMPLETE only removeAuthed() ran, so
    queued responses for the dead handle (the web app fires a GETCONFIGVALUES +
    PRESET burst on connect) lingered. ble_notify() later drained one and called
    att_server_notify_SAFE(dead_handle, ...), which busy-waited on
    att_server_can_send_packet_now() -- false forever for a dropped connection --
    wedging the Bluetooth task. That task also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
    [ble.cpp]
2026-09-07 Move stale-packet cleanup to DISCONNECTION_COMPLETE
    The previous commit added a bounded 250ms wait + early return to
    att_server_notify_SAFE as the primary way to shed queued packets for a
    dropped connection. That stalls the Bluetooth task 250ms per leftover
    packet and, more importantly, does not actually clear the queue at the
    source: the DISCONNECTION_COMPLETE handler only ran removeAuthed(), so
    the web app's connect burst (GETCONFIGVALUES + PRESET) left multiple
    dead-handle packets queued for ble_notify() to burn through.
    Clean up at the source: call packetMover::clearPacketsForHandle() from
    DISCONNECTION_COMPLETE (same run-loop context removeAuthed() already ran
    in). The common case now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
    [ble.cpp]
2026-09-08 decided i didn't want this comment
    [ble.cpp]
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2026-09-11 Weak connection check on ota
    broke out Update.writeStream into it's own function to track a slow connection
    [ble.cpp, main.cpp]
2026-09-11 reverted text changed to rollback
    [ble.cpp]
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2026-09-13 Bug fix for the code for the boot button air up things being disabled
    [main.cpp]
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
